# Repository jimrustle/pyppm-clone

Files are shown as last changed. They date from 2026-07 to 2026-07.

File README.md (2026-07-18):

#

This project is a modern update of [https://github.com/geekysuavo/pyppm](https://github.com/geekysuavo/pyppm).

All design credits go to geekysuavo.

see kicad/ppm-clone.pdf for schematic

# Changes

This project implements pyppm ver 2.2 in KiCAD 10.0 instead of gEDA.

- The CTX02-13665 and LT3439 have been replaced with a Wurth 78931812512 and TI SN6505BDBV due to the CTX02 becoming obsoleted

# Notes

No changes so far. Any parts changes will be performed in separate branches.

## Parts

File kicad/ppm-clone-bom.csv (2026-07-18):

Reference | Value | Footprint | Qty | LCSC P/N | Notes | Check | Digikey PN | LCSC qty
C1,C29,CB52,CT14 | 1u | Capacitor_SMD:C_0603_1608Metric_Pad1.08x0.95mm_HandSolder | 4 | C5673 | 25 V X5R | x | 490-5307-1-ND | 50
C2,C3 | 27p | Capacitor_SMD:C_0603_1608Metric_Pad1.08x0.95mm_HandSolder | 2 | C107045 |  | x | 490-1413-1-ND
C4,C5,C15,C18,C27,CB1,CB2,CB9,CB10,CB12,CB13,CB15,CB16,CB18,CB20,CB22,CB24,CB26,CB28,CB30,CB32,CB34,CB36,CB38,CB40,CB42,CB44,CB46,CB48,CB50,CB53,CB55,CB57,CB59,CB61,CB63,CT10 | 100n | Capacitor_SMD:C_0603_1608Metric_Pad1.08x0.95mm_HandSolder | 37 | C14663 |  | x | 490-1532-1-ND
C7 | 2.2n / 1kV | Capacitor_SMD:C_1206_3216Metric_Pad1.33x1.80mm_HandSolder | 1 | C9191 |  | x | 478-2953-1-ND
C8,C9,C11,C12 | 15u | Capacitor_SMD:C_0805_2012Metric_Pad1.18x1.45mm_HandSolder | 4 |  |  |  | 445-3927-1-ND
C10,C13,C14,C16,C19,C20,C21,C22,C23,C24,C25,C26,C28,C30 | 10n | Capacitor_SMD:C_0603_1608Metric_Pad1.08x0.95mm_HandSolder | 14 | C115056 |  | x | 445-2664-1-ND
C17 | 220p | Capacitor_SMD:C_0603_1608Metric_Pad1.08x0.95mm_HandSolder | 1 | C302060 | film to mlcc | x | PCF1445CT-ND
CB3,CB4,CB7,CB8,CB11,CB14,CB17,CB21,CB25,CB27,CB29,CB31,CB33,CB35,CB37,CB39,CB41,CB43,CB45,CB47,CB49,CB51,CB54,CB56,CB58,CB60,CB62 | 10u | Capacitor_SMD:C_0603_1608Metric_Pad1.08x0.95mm_HandSolder | 27 | C96446 | tantalum to mlcc | x | 511-1683-1-ND
CB5,CB6,CT16 | 4.7u | Capacitor_SMD:C_0603_1608Metric_Pad1.08x0.95mm_HandSolder | 3 | C19666 |  | x | 490-7199-1-ND
CB19,CB23 | 100u | Capacitor_SMD:CP_Elec_5x5.3 | 2 | C134722 | tant poly to alum | x | P16641CT-ND
CT1 | 150p | Capacitor_SMD:C_0603_1608Metric_Pad1.08x0.95mm_HandSolder | 1 | C107038 | film to mlcc | x | PCF1461CT-ND
CT2 | 330p | Capacitor_SMD:C_0603_1608Metric_Pad1.08x0.95mm_HandSolder | 1 | C1664 | film to mlcc | x | PCF1465CT-ND
CT3 | 680p | Capacitor_SMD:C_0603_1608Metric_Pad1.08x0.95mm_HandSolder | 1 | C107055 | film to mlcc | x | PCF1451CT-ND
CT4 | 1.5n | Capacitor_SMD:C_0603_1608Metric_Pad1.08x0.95mm_HandSolder | 1 | C576797 | film to mlcc | x | PCF1455CT-ND
CT5 | 3.3n | Capacitor_SMD:C_0603_1608Metric_Pad1.08x0.95mm_HandSolder | 1 | C3877267 | film to mlcc | x | PCF1171CT-ND
CT6 | 6.8n | Capacitor_SMD:C_0603_1608Metric_Pad1.08x0.95mm_HandSolder | 1 | C307492 | film to mlcc | x | PCF1175CT-ND
CT7 | 15n | Capacitor_SMD:C_0603_1608Metric_Pad1.08x0.95mm_HandSolder | 1 | C2833636 | film to mlcc | x | PCF1179CT-ND
CT8 | 33n | Capacitor_SMD:C_0603_1608Metric_Pad1.08x0.95mm_HandSolder | 1 | C106856 | film to mlcc | x | PCF1183CT-ND
CT9 | 68n | Capacitor_SMD:C_0603_1608Metric_Pad1.08x0.95mm_HandSolder | 1 | C107098 | film to mlcc | x | PCF1187CT-ND
CT11 | 220n | Capacitor_SMD:C_0603_1608Metric_Pad1.08x0.95mm_HandSolder | 1 | C344195 | film to mlcc | x | PCF1128CT-ND
CT12 | 330n | Capacitor_SMD:C_0603_1608Metric_Pad1.08x0.95mm_HandSolder | 1 | C282682 | film to mlcc | x | PCF1129CT-ND
CT13 | 680n | Capacitor_SMD:C_0603_1608Metric_Pad1.08x0.95mm_HandSolder | 1 | C5143539 | film to mlcc | x | PCF1131CT-ND
CT15 | 2.2u | Capacitor_SMD:C_0603_1608Metric_Pad1.08x0.95mm_HandSolder | 1 | C5184421 |  | x | 490-3296-1-ND
D3,D4,D6,D7 | BAS40-04 | Package_TO_SOT_SMD:SOT-23 | 4 | C40919 |  | x | BAS40-04-V-GS08CT-ND
D5 | BAV199 | Package_TO_SOT_SMD:SOT-23 | 1 | C40919 | bav199 | x | 568-1619-1-ND
D8 | S5GC-13-F | Diode_SMD:D_SMC-RM10_Universal_Handsoldering | 1 | C211400 |  | x | S5GC-FDICT-ND
D9 | SMDJ45A | Diode_SMD:D_SMC-RM10_Universal_Handsoldering | 1 | C4154731 |  | x | SMDJ45ACT-ND
D10 | BAT54W | Package_TO_SOT_SMD:SOT-323_SC-70 | 1 | C8657 | slower | x | SD101AWSTPMSCT-ND
DL1,DL2,DL3,DL4,DL5,DL6,DL7,DL8 | LED | LED_SMD:LED_0805_2012Metric_Pad1.15x1.40mm_HandSolder | 8 | C22371297 | 10 mA, 0603 | x | 160-1828-1-ND
J1 | USB_C_Receptacle_USB2.0_14P | Connector_USB:USB_C_Receptacle_HCTL_HC-TYPE-C-16P-01A | 1 | C2894897 |  | x
J2 | Barrel_Jack |  | 1 |  |  | x
K1 | G6A | Relay_THT:Relay_DPDT_Omron_G6A | 1 | C146834 |  | x | Z123-ND
L1,L2 | 33u | ppm-clone:SDR6603 | 2 |  | OUT OF STOCK
L3,L4,L5 | BLM18PG121SN1D | Inductor_SMD:L_0603_1608Metric_Pad1.05x0.95mm_HandSolder | 3 | C14709 |  | x | 490-1037-1-ND
LJ1,LJ2,LJ3 | Screw_Terminal_01x02 | TerminalBlock_TE-Connectivity:TerminalBlock_TE_282834-2_1x02_P2.54mm_Horizontal | 3 | C8465 |  | x
Q1 | STD20NF06T4 | Package_TO_SOT_SMD:TO-252-2 | 1 | C22366765 |  | x | IRLR024NPBFCT-ND
Q2 | DMN2230U | Package_TO_SOT_SMD:SOT-23 | 1 | C516590 | RDS worse |  | FDN327NCT-ND
R1,R2 | 22 | Resistor_SMD:R_0603_1608Metric_Pad0.98x0.95mm_HandSolder | 2 | C23345 |  |  | P22.0HCT-ND
R3,R4,R7,R20,R28,R29,R30,R31,R39,R40,R42,R49,R52 | 10k | Resistor_SMD:R_0603_1608Metric_Pad0.98x0.95mm_HandSolder | 13 | C2930027 |  |  | P10.0KHCT-ND
R5,R6 | 5.1k | Resistor_SMD:R_0603_1608Metric_Pad0.98x0.95mm_HandSolder | 2 | C2907114
R10,R12 | 1.05k | Resistor_SMD:R_0603_1608Metric_Pad0.98x0.95mm_HandSolder | 2 | C2930047 |  |  | P1.05KHCT-ND
R11,R13,R22,R23,R37,R51 | 1k | Resistor_SMD:R_0603_1608Metric_Pad0.98x0.95mm_HandSolder | 6 | C2907113 |  |  | P1.00KHCT-ND
R14,R15,R17,R19,R36 | 100k | Resistor_SMD:R_0603_1608Metric_Pad0.98x0.95mm_HandSolder | 5 | C14675 |  |  | P100KHCT-ND
R16 | 1.3M | Resistor_SMD:R_0603_1608Metric_Pad0.98x0.95mm_HandSolder | 1 | C2974026 |  |  | P1.3MGCT-ND
R18 | 1.5M | Resistor_SMD:R_0603_1608Metric_Pad0.98x0.95mm_HandSolder | 1 | C4172 |  |  | P1.5MGCT-ND
R21,R24 | 3.16k | Resistor_SMD:R_0603_1608Metric_Pad0.98x0.95mm_HandSolder | 2 | C2930087 |  |  | P3.16KHCT-ND
R25,R26,R27 | 330 | Resistor_SMD:R_0603_1608Metric_Pad0.98x0.95mm_HandSolder | 3 | C23138 |  |  | P330HCT-ND
R32,R33,R41 | 49.9 | Resistor_SMD:R_0603_1608Metric_Pad0.98x0.95mm_HandSolder | 3 | C2930110 |  |  | P49.9DBCT-ND
R34,R35,R44,R47 | 1M | Resistor_SMD:R_0603_1608Metric_Pad0.98x0.95mm_HandSolder | 4 | C22935 |  |  | A102234CT-ND
R38 | 10 | Resistor_SMD:R_0603_1608Metric_Pad0.98x0.95mm_HandSolder | 1 | C22859 |  |  | CRT0603-BY-10R0ELFCT-ND
R43,R46 | 0 | Resistor_SMD:R_0603_1608Metric_Pad0.98x0.95mm_HandSolder | 2 | C21189 |  |  | P0.0GCT-ND
R45,R48 | 715 | Resistor_SMD:R_0603_1608Metric_Pad0.98x0.95mm_HandSolder | 2 | C2998136 |  |  | P715DBCT-ND
R50 | 33.2 | Resistor_SMD:R_0603_1608Metric_Pad0.98x0.95mm_HandSolder | 1 | C2930093 |  |  | P33.2HCT-ND
RF1 | 14.3k | Resistor_SMD:R_0603_1608Metric_Pad0.98x0.95mm_HandSolder | 1 | C2933145 |  |  | P14.3KHCT-ND
RF2 | 15.4k | Resistor_SMD:R_0603_1608Metric_Pad0.98x0.95mm_HandSolder | 1 | C2933150 |  |  | P15.4KHCT-ND
RF3 | 45.3k | Resistor_SMD:R_0603_1608Metric_Pad0.98x0.95mm_HandSolder | 1 | C2933224 |  |  | P45.3KHCT-ND
RF4 | 5.49k | Resistor_SMD:R_0603_1608Metric_Pad0.98x0.95mm_HandSolder | 1 | C3000723 |  |  | P5.49KHCT-ND
RF5 | 6.04k | Resistor_SMD:R_0603_1608Metric_Pad0.98x0.95mm_HandSolder | 1 | C25977 |  |  | P6.04KHCT-ND
RF6 | 17.4k | Resistor_SMD:R_0603_1608Metric_Pad0.98x0.95mm_HandSolder | 1 | C2930069 |  |  | P17.4KHCT-ND
RF7 | 13.3k | Resistor_SMD:R_0603_1608Metric_Pad0.98x0.95mm_HandSolder | 1 | C2933140 |  |  | P13.3KHCT-ND
RF8 | 5.23k | Resistor_SMD:R_0603_1608Metric_Pad0.98x0.95mm_HandSolder | 1 | C2930111 |  |  | P5.23KHCT-ND
RF9 | 232k | Resistor_SMD:R_0603_1608Metric_Pad0.98x0.95mm_HandSolder | 1 | C2998117 |  |  | P232KHCT-ND
RF10 | 2k | Resistor_SMD:R_0603_1608Metric_Pad0.98x0.95mm_HandSolder | 1 | C2907137 |  |  | P2.00KHCT-ND
RF11 | 732 | Resistor_SMD:R_0603_1608Metric_Pad0.98x0.95mm_HandSolder | 1 | C245063 |  |  | P732HCT-ND
RF12 | 34.8k | Resistor_SMD:R_0603_1608Metric_Pad0.98x0.95mm_HandSolder | 1 | C23141 |  |  | P34.8KHCT-ND
RL1,RL2,RL3,RL4,RL5,RL6,RL7,RL8 | 100 | Resistor_SMD:R_0603_1608Metric_Pad0.98x0.95mm_HandSolder | 8 |  | 500 ohm |  | P604HCT-ND
RY1 | ACSL-6300 | Package_SO:SO-16_3.9x9.9mm_P1.27mm | 1 | C6800668 |  |  | 516-2221-1-ND
SW1,SW2 | SW_Push | Button_Switch_SMD:SW_SPST_B3S-1000 | 2 |  | OUT OF STOCK
T1 | 78931812512 | Transformer_SMD:Transformer_Wuerth_750315371 | 1 |  | OUT OF STOCK
U1 | ATmega32U4-A | Package_QFP:TQFP-44_10x10mm_P0.8mm | 1 | C2052746 |  |  | ATMEGA32U4-AU-ND | 3
U3 | SN6505BDBV | Package_TO_SOT_SMD:SOT-23-6 | 1 | C2156022 |  |  | LT3439EFE#PBF-ND | 3
U4 | LT1761-5 | Package_TO_SOT_SMD:TSOT-23-5 | 1 | C655160 |  |  | LT1761ES5-5#TRMPBFCT-ND | 3
U5 | LT1964-5 | Package_TO_SOT_SMD:TSOT-23-5 | 1 | C5357091 |  |  | LT1964ES5-5#TRMPBFCT-ND | 3
U6 | LT1761-SD | Package_TO_SOT_SMD:TSOT-23-5 | 1 | C117432 |  |  | LT1761ES5-SD#TRMPBFCT-ND | 3
U7 | LT1964-SD | Package_TO_SOT_SMD:TSOT-23-5 | 1 | C117431 |  |  | LT1964ES5-SD#TRMPBFCT-ND | 3
U8 | LTC2909 | Package_TO_SOT_SMD:TSOT-23-8_HandSoldering | 1 |  | OUT OF STOCK |  | LTC2909CTS8-5#TRMPBFCT-ND
U9 | LT1764AEQ | Package_TO_SOT_SMD:TO-263-5_TabPin3 | 1 | C459712 |  |  | LT1764AEQ#TRPBFCT-ND | 3
U10 | LT3015xQ-5 | Package_TO_SOT_SMD:TO-263-5_TabPin3 | 1 | C666317 |  |  | LT3015EQ#PBF-ND | 3
U12,U13 | ADG714 | Package_SO:TSSOP-24_4.4x7.8mm_P0.65mm | 2 | C462201 |  |  | ADG714BRUZ-REEL7CT-ND | 3
U14 | AD8428 | Package_SO:SOIC-8_3.9x4.9mm_P1.27mm | 1 |  | OUT OF STOCK |  | AD8428ARZ-ND
U15 | AD8597 | Package_SO:SOIC-8_3.9x4.9mm_P1.27mm | 1 | C209450 |  |  | AD8597ARZ-ND | 3
U16 | OP462 | Package_SO:TSSOP-14_4.4x5mm_P0.65mm | 1 |  | OUT OF STOCK |  | OP462HRUZ-REELCT-ND
U17 | ADA4841-1YRJ | Package_TO_SOT_SMD:SOT-23-6 | 1 | C578930 |  |  | ADA4841-1YRJZ-R7CT-ND | 3
U18 | AD7680ARMZ | Package_TO_SOT_SMD:SOT-23-6 | 1 | C578464 |  |  | AD7680ARJZ-REEL7CT-ND | 3
U19 | AD5752 | Package_SO:HTSSOP-24-1EP_4.4x7.8mm_P0.65mm_EP3.2x5mm | 1 |  | OUT OF STOCK |  | AD5752RBREZ-ND
U20 | ADR4520 | Package_SO:SOIC-8_3.9x4.9mm_P1.27mm | 1 | C579305 |  |  | ADR4520BRZ-ND | 3
U21 | LT1206CS8 | Package_SO:SO-8_3.9x4.9mm_P1.27mm | 1 | C579690 |  |  | LT1206CS8#PBF-ND | 3
U22 | LT1210 | Package_TO_SOT_SMD:TO-263-7_TabPin4 | 1 | C1349277 |  |  | LT1210CR#PBF-ND | 3
U23 | FAN3111E | Package_TO_SOT_SMD:SOT-23-5 | 1 | C719836 |  |  | FAN3111ESXCT-ND | 15
Y1 | 16M | Crystal:Crystal_SMD_Abracon_ABM7-2Pin_6.0x3.5mm | 1 | 535-9840-1-ND | OUT OF STOCK |  | 535-9840-1-ND

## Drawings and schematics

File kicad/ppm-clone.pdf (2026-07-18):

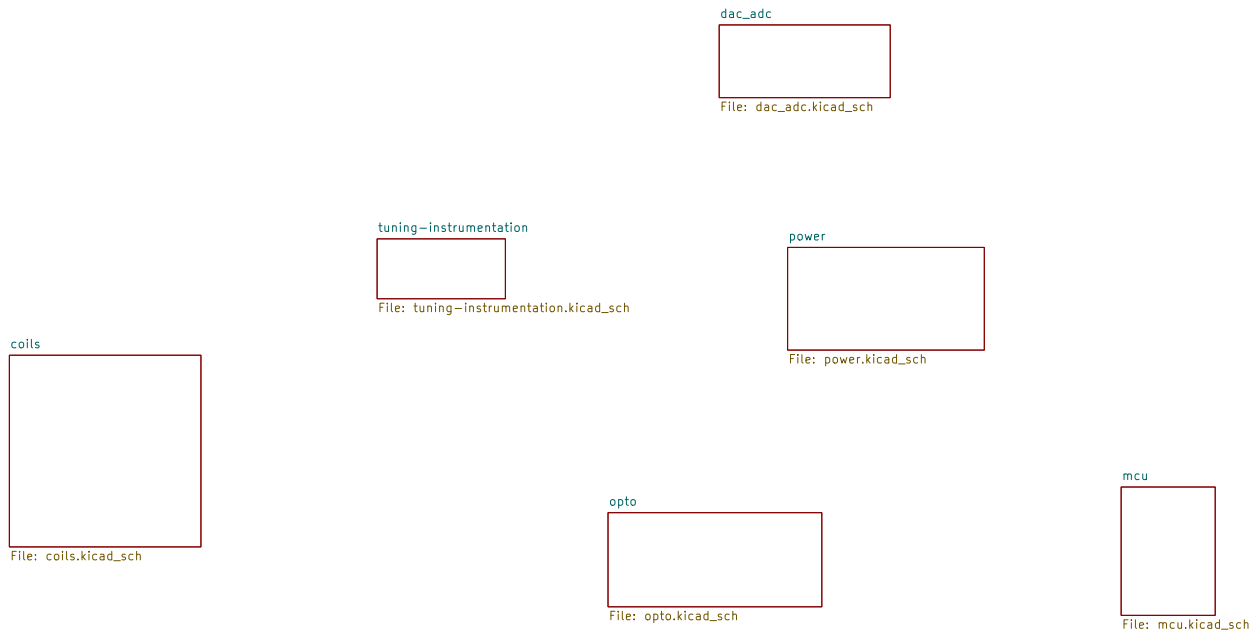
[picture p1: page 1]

Size: A4 | Rev:
KiCad E.D.A. 10.0.1 | Id: 1/7

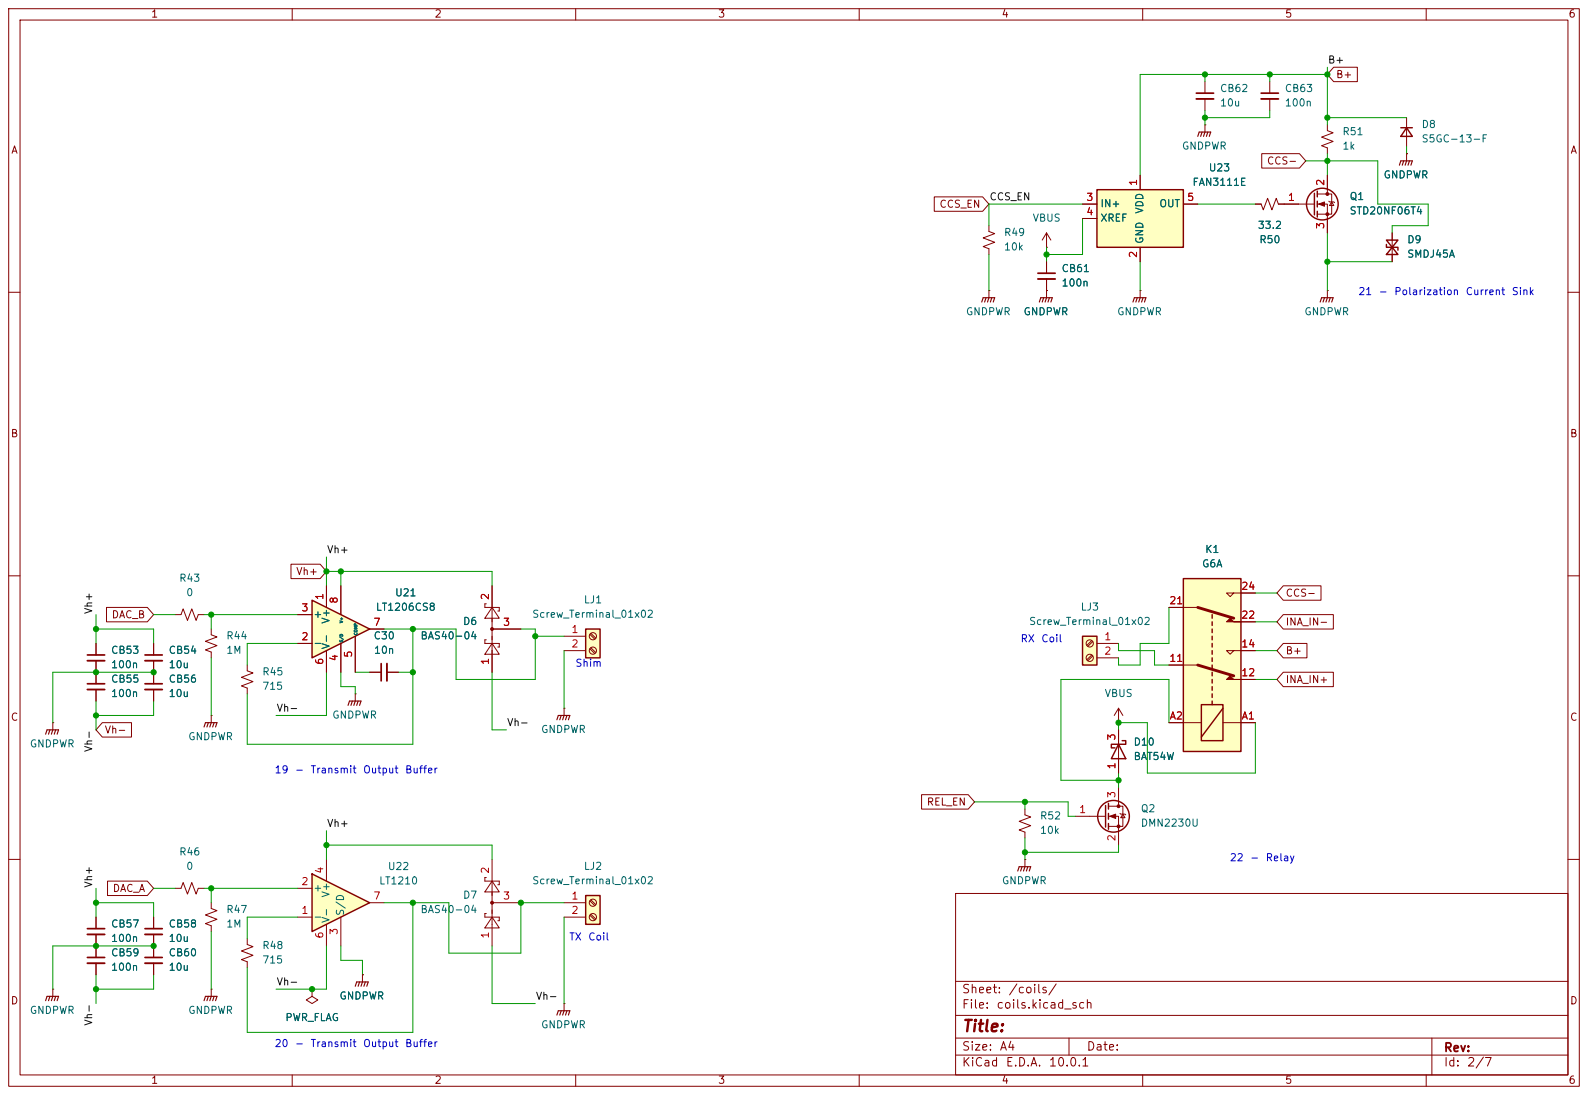
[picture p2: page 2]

21 - Polarization Current Sink Shim

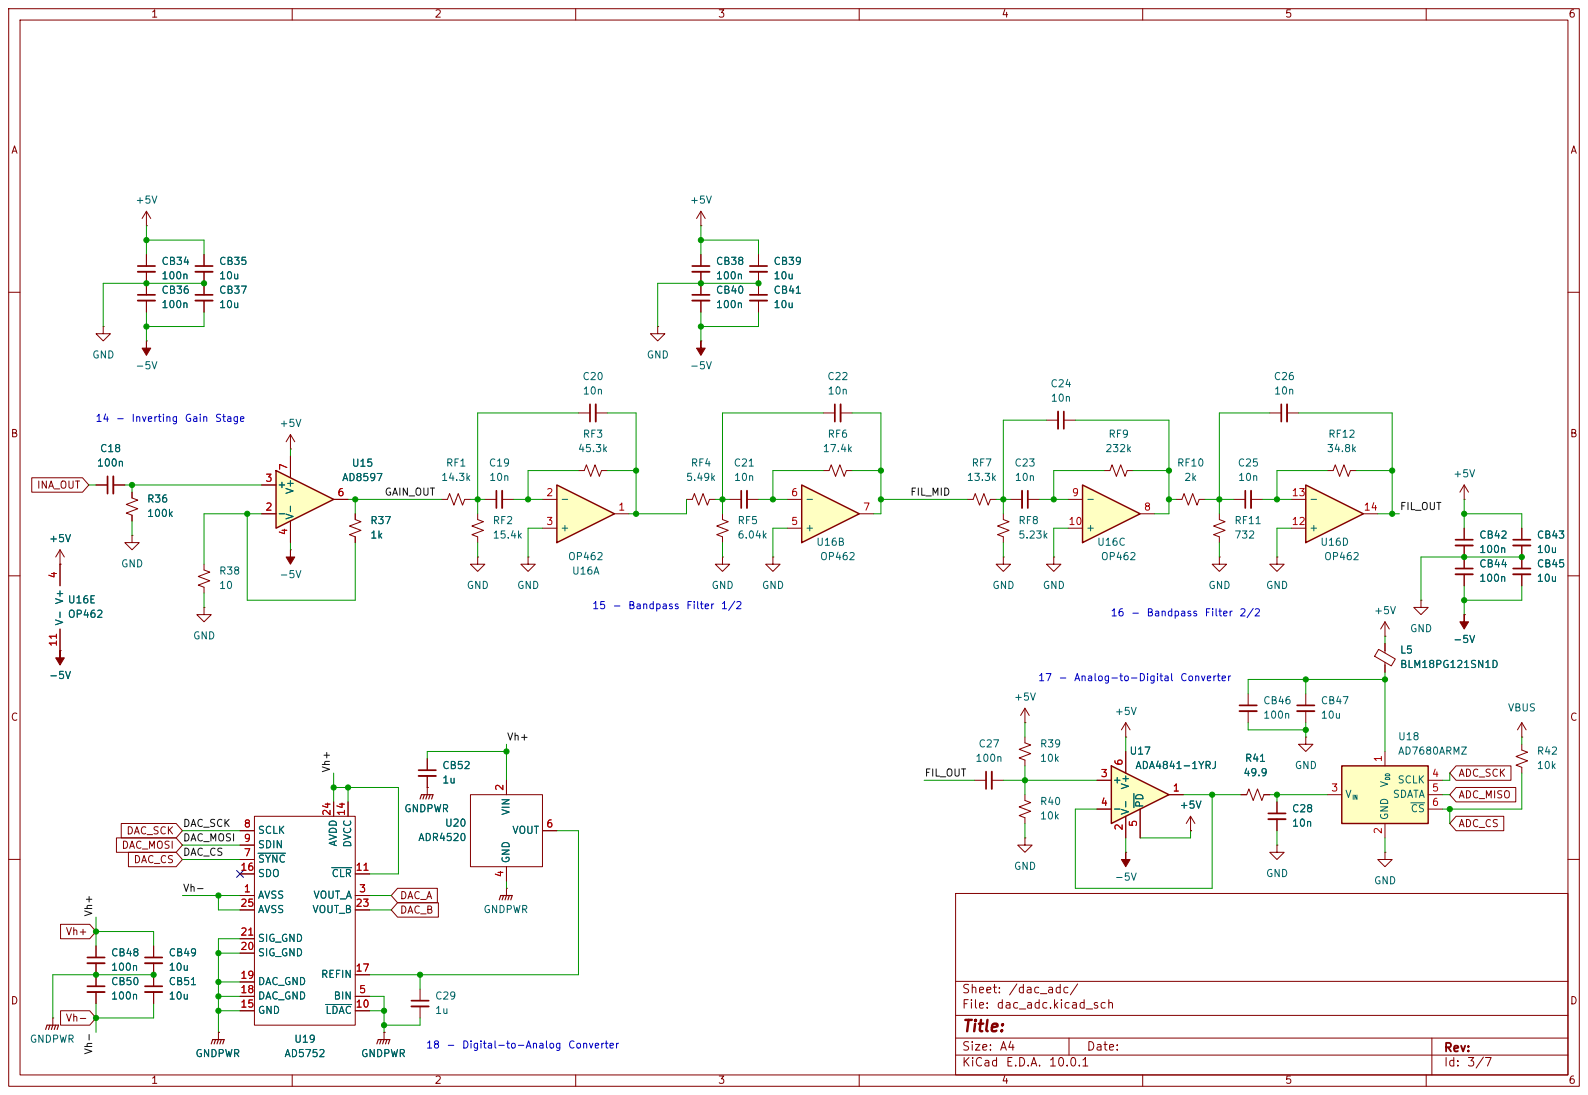
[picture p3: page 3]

17 - Analog-to-Digital Converter 14 - Inverting Gain Stage

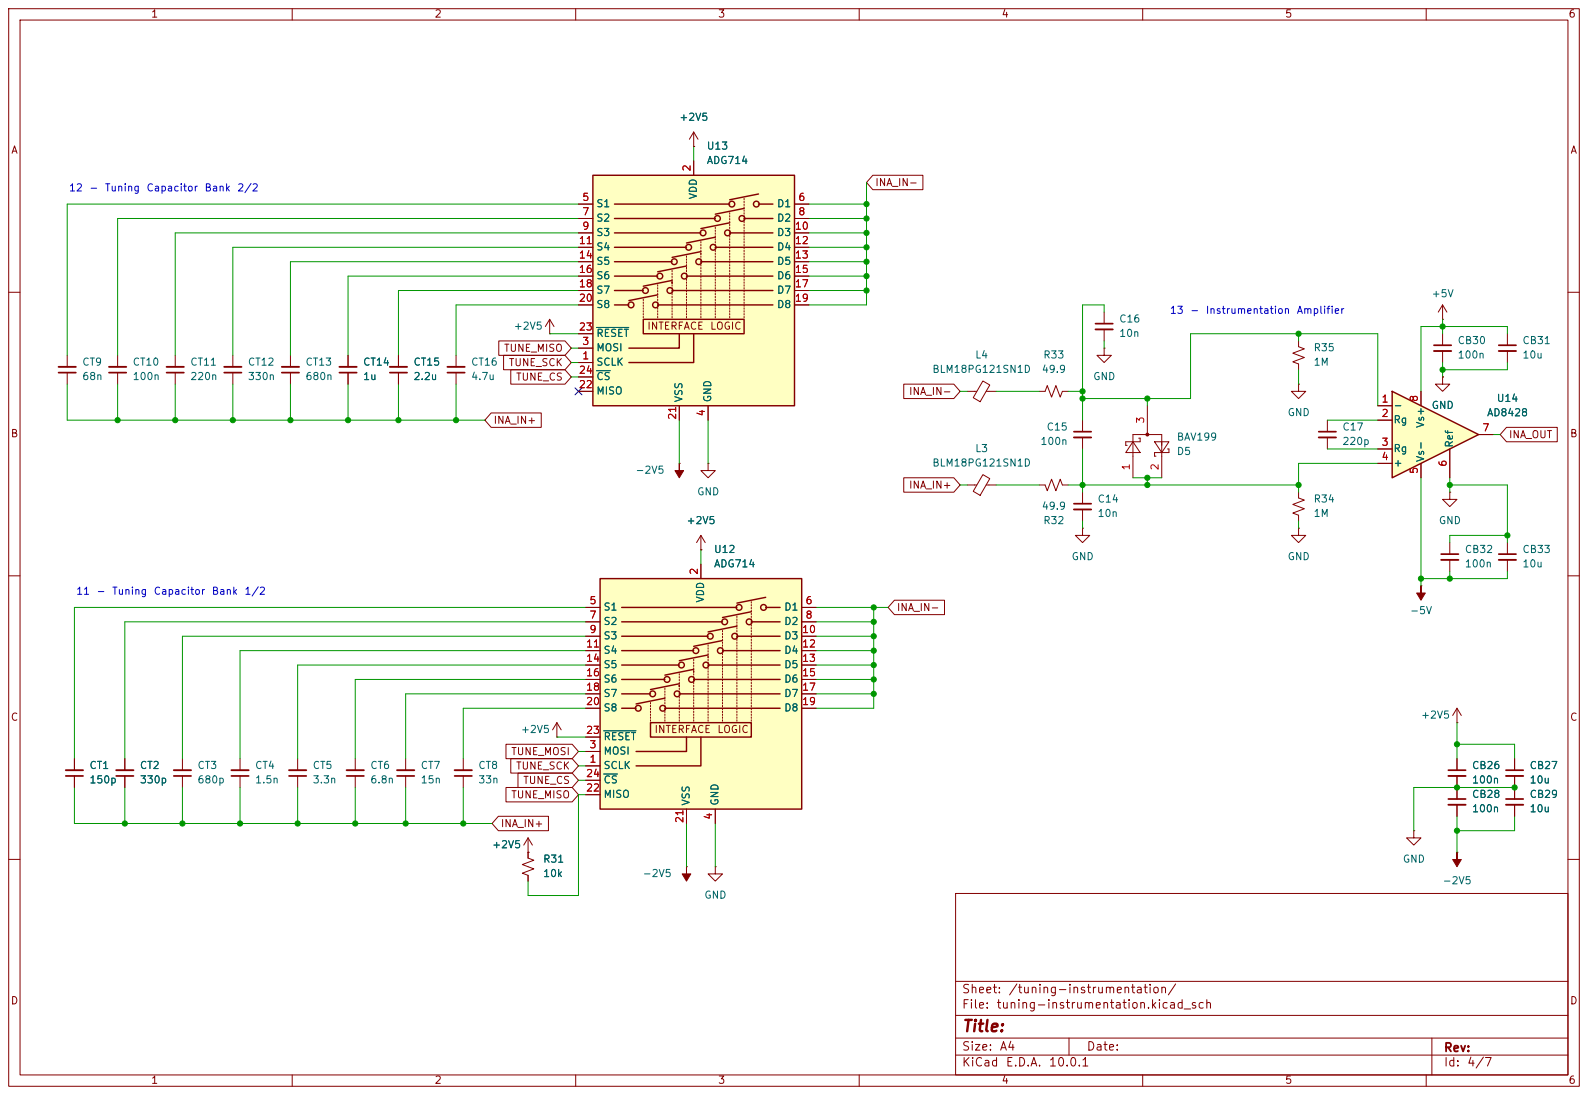
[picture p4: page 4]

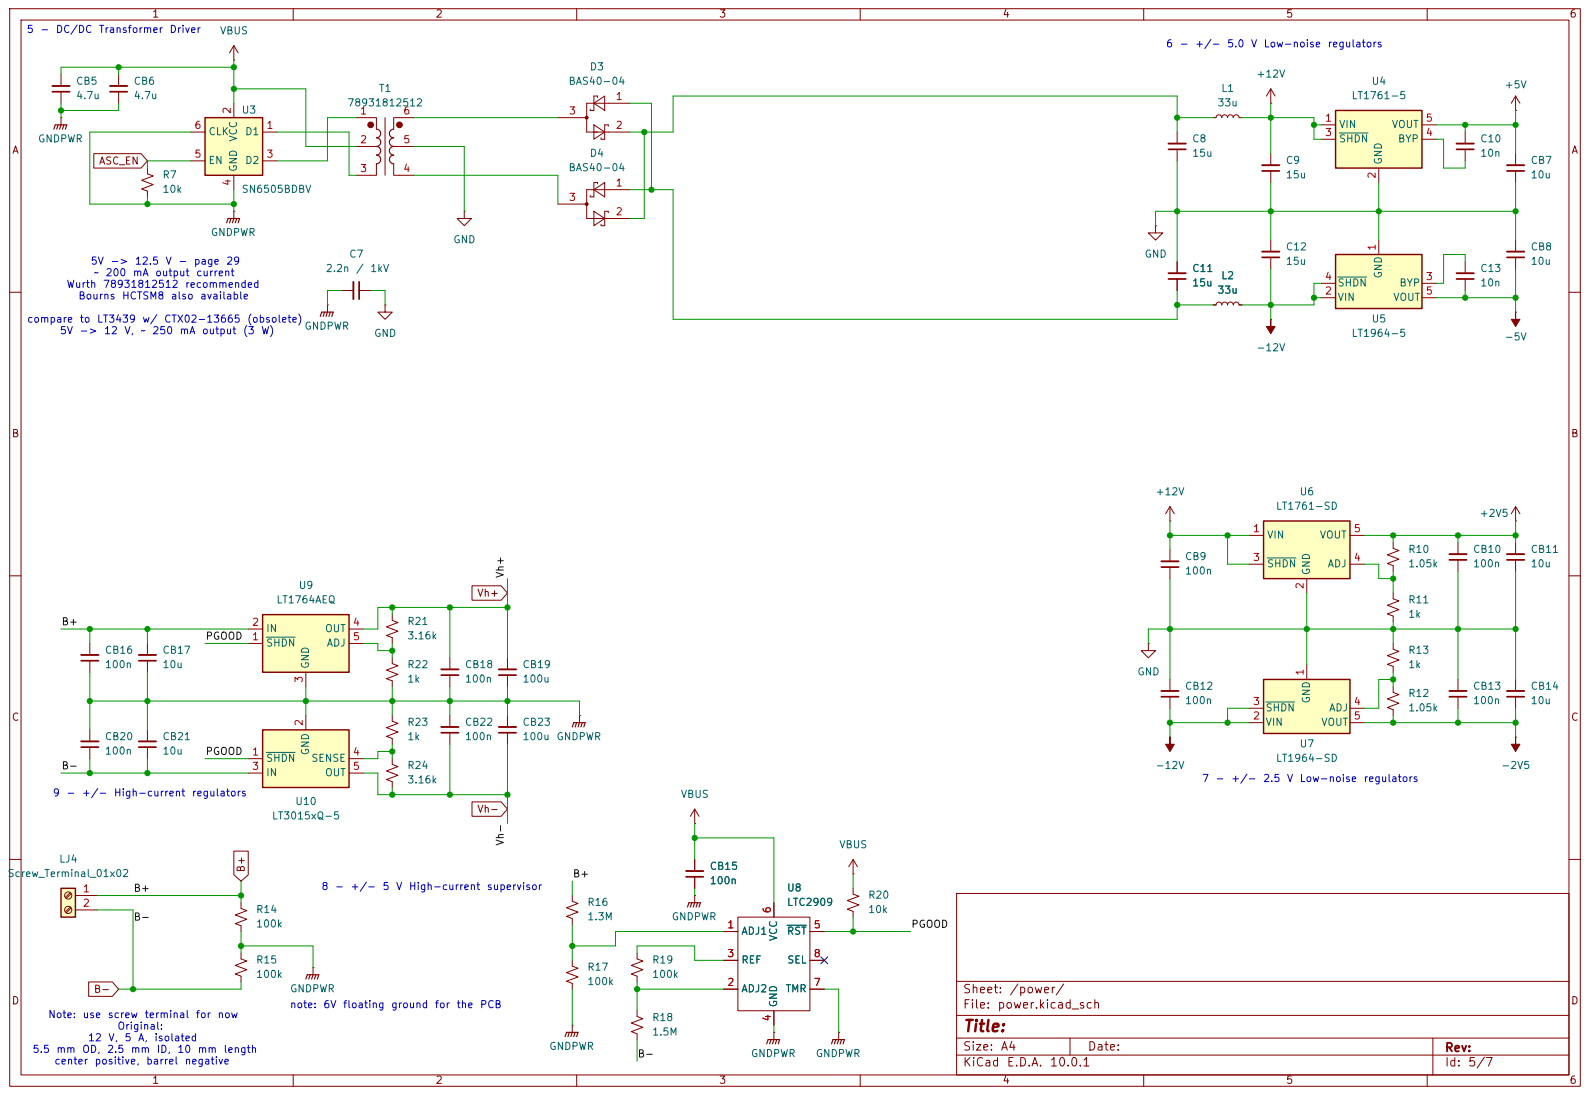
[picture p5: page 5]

6 - +/- 5.0 V Low-noise regulators 5 - DC/DC Transformer Driver 5V -> 12.5 V - page 29
3 D4 BAS40-04 R23

compare to LT3439 w/ CTX02-13665 (obsolete) 5V -> 12 V, ~ 250 mA output (3 W) Note: use screw terminal for now

~ 200 mA output current Wurth 78931812512 recommended Bourns HCTSM8 also available

Original: 12 V, 5 A, isolated 5.5 mm OD, 2.5 mm ID, 10 mm length

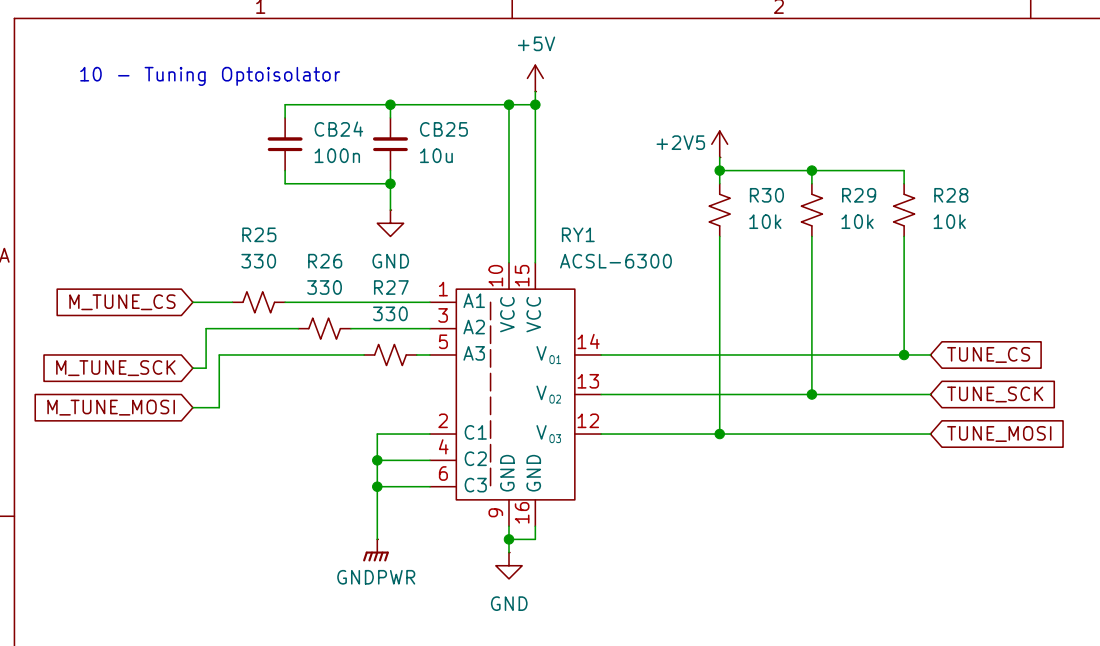
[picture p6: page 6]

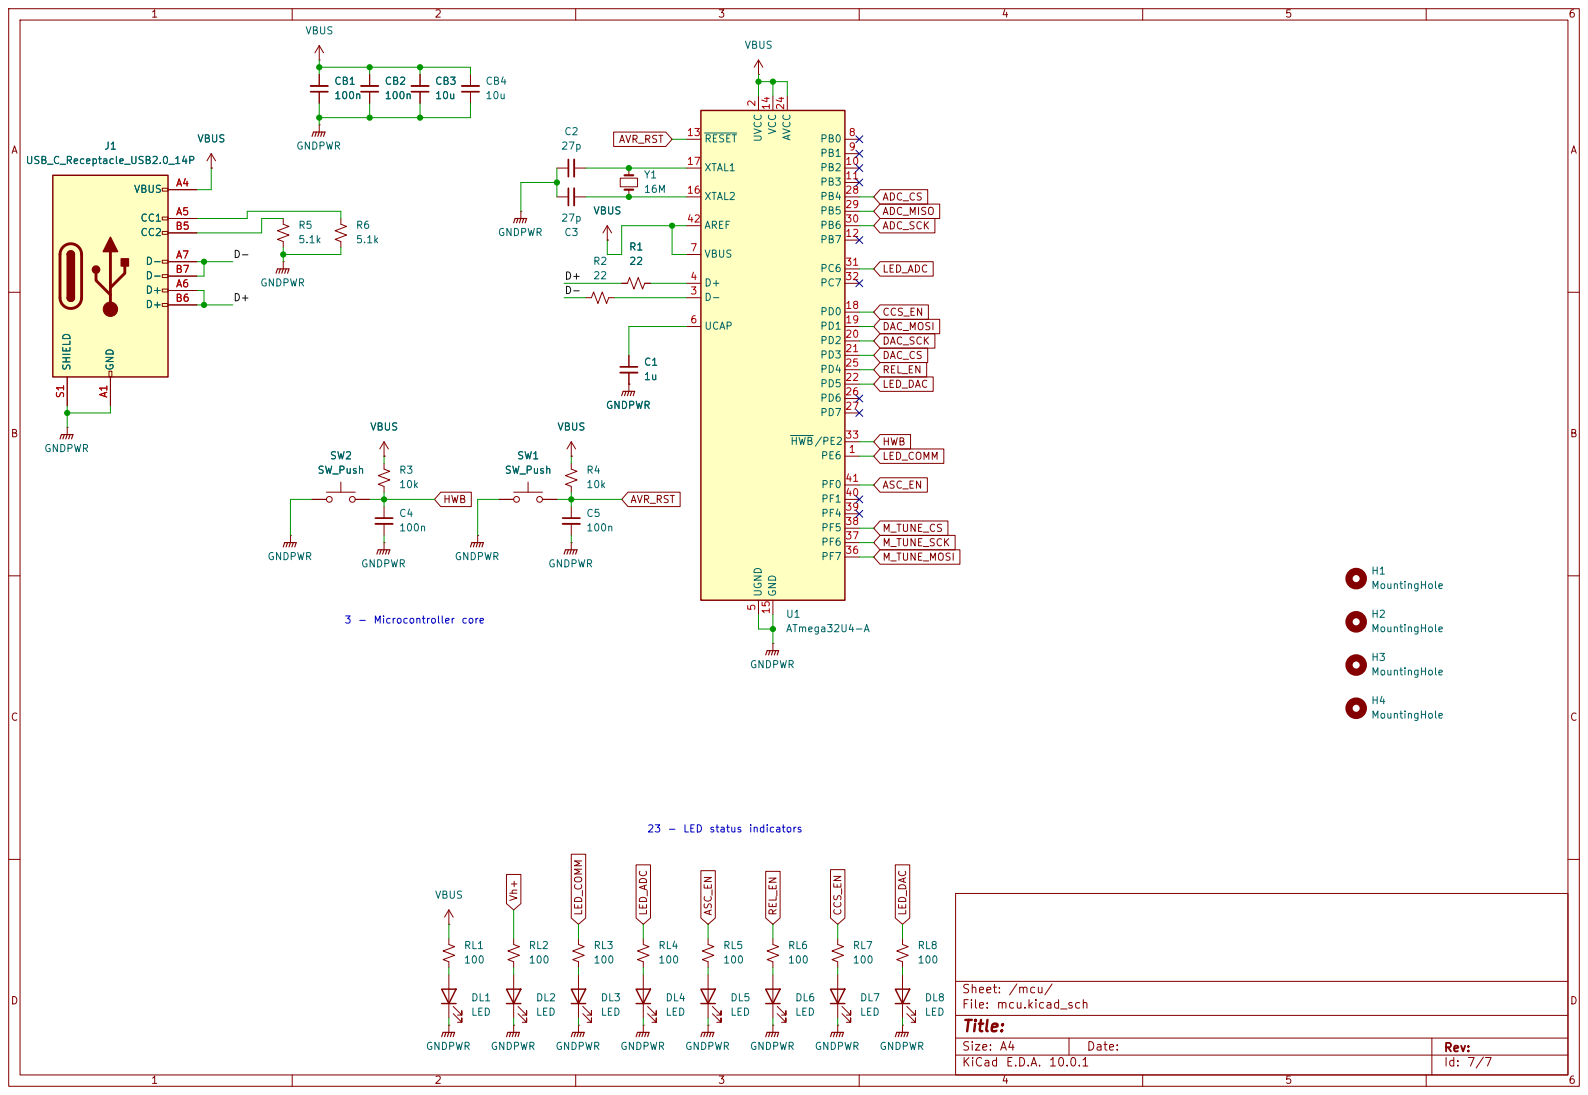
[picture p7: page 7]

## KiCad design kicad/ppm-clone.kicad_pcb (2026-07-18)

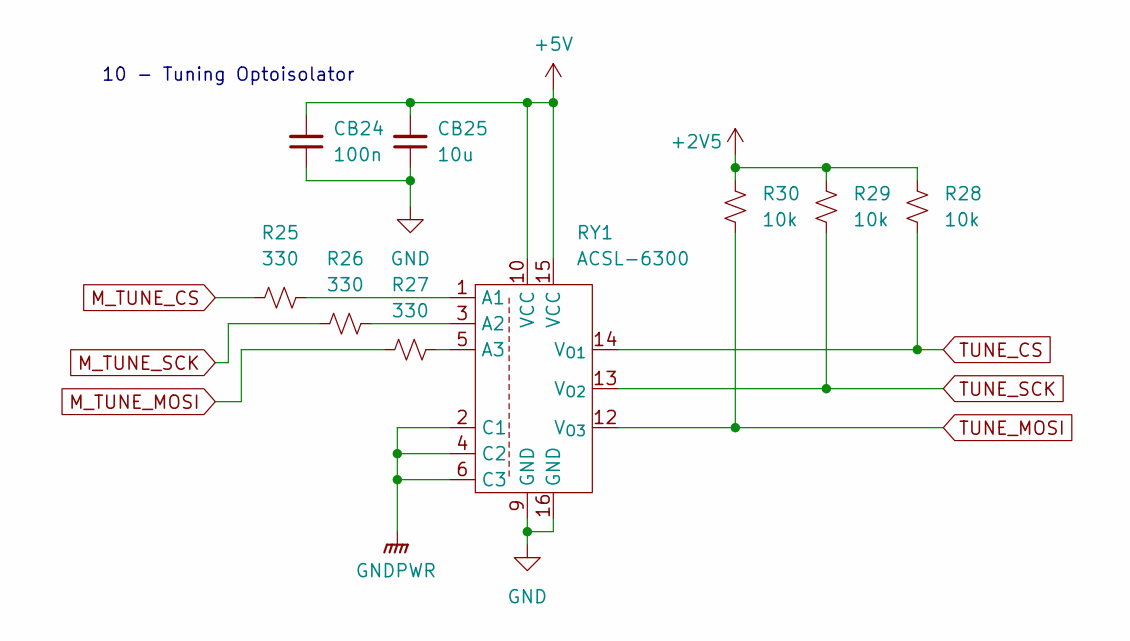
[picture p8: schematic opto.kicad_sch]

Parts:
CB24: 100n; C_0603_1608Metric_Pad1.08x0.95mm_HandSolder
CB25: 10u; C_0603_1608Metric_Pad1.08x0.95mm_HandSolder
R25, R26, R27: 330; R_0603_1608Metric_Pad0.98x0.95mm_HandSolder
R28, R29, R30: 10k; R_0603_1608Metric_Pad0.98x0.95mm_HandSolder
RY1: ACSL-6300; SO-16_3.9x9.9mm_P1.27mm

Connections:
+2V5: R28.1, R29.1, R30.1; also elsewhere on the board
+5V: CB24.2, CB25.2, RY1.10 (VCC), RY1.15 (VCC); also elsewhere on the board
GND: CB24.1, CB25.1, RY1.9 (GND), RY1.16 (GND); also elsewhere on the board
GNDPWR: RY1.2 (C1), RY1.4 (C2), RY1.6 (C3); also elsewhere on the board
M_TUNE_CS: R25.2; also elsewhere on the board
M_TUNE_MOSI: R27.2; also elsewhere on the board
M_TUNE_SCK: R26.2; also elsewhere on the board
unnamed: R25.1, RY1.1 (A1)
unnamed: R26.1, RY1.3 (A2)
unnamed: R27.1, RY1.5 (A3)
TUNE_CS: R28.2, RY1.14 (V_{O1}); also elsewhere on the board
TUNE_MOSI: R30.2, RY1.12 (V_{O3}); also elsewhere on the board
TUNE_SCK: R29.2, RY1.13 (V_{O2}); also elsewhere on the board

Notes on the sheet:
10 - Tuning Optoisolator

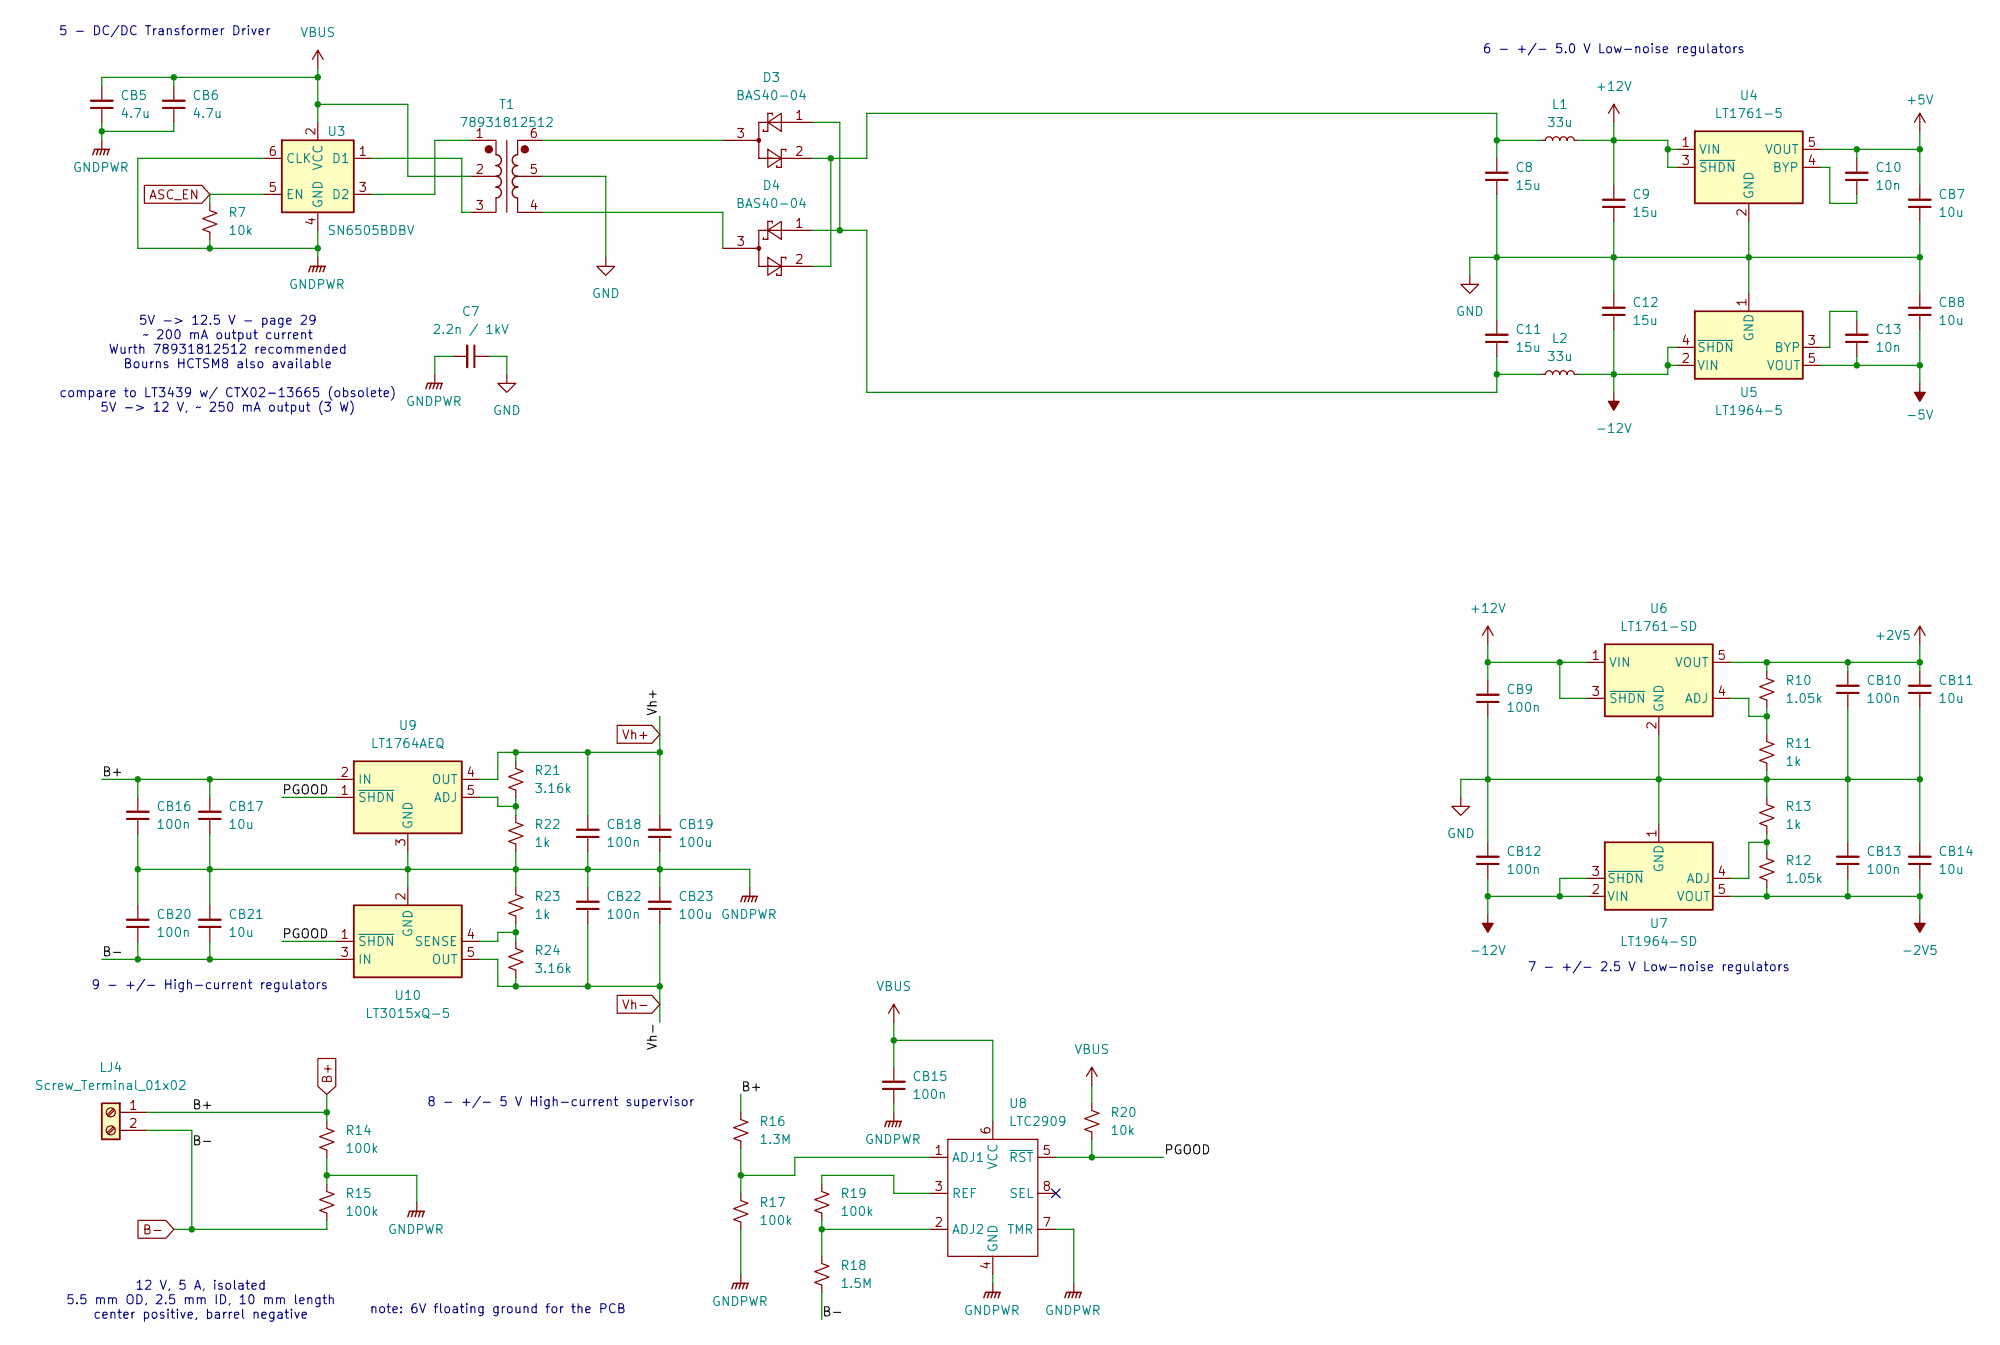
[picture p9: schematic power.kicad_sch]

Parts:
C7: 2.2n / 1kV; C_1206_3216Metric_Pad1.33x1.80mm_HandSolder
C8, C9, C11, C12: 15u; C_2220_5750Metric_Pad1.97x5.40mm_HandSolder
C10, C13: 10n; C_0603_1608Metric_Pad1.08x0.95mm_HandSolder
CB5, CB6: 4.7u; C_0603_1608Metric_Pad1.08x0.95mm_HandSolder
CB7, CB8, CB11, CB14, CB17, CB21: 10u; C_0603_1608Metric_Pad1.08x0.95mm_HandSolder
CB9, CB10, CB12, CB13, CB15, CB16, CB18, CB20, CB22: 100n; C_0603_1608Metric_Pad1.08x0.95mm_HandSolder
CB19, CB23: 100u; CP_Elec_5x5.3
D3, D4: BAS40-04; SOT-23
L1, L2: 33u; SDR6603
LJ4: Screw_Terminal_01x02; TerminalBlock_bornier-2_P5.08mm
R7, R20: 10k; R_0603_1608Metric_Pad0.98x0.95mm_HandSolder
R10, R12: 1.05k; R_0603_1608Metric_Pad0.98x0.95mm_HandSolder
R11, R13, R22, R23: 1k; R_0603_1608Metric_Pad0.98x0.95mm_HandSolder
R14, R15, R17, R19: 100k; R_0603_1608Metric_Pad0.98x0.95mm_HandSolder
R16: 1.3M; R_0603_1608Metric_Pad0.98x0.95mm_HandSolder
R18: 1.5M; R_0603_1608Metric_Pad0.98x0.95mm_HandSolder
R21, R24: 3.16k; R_0603_1608Metric_Pad0.98x0.95mm_HandSolder
T1: 78931812512; Transformer_Wuerth_750315371
U3: SN6505BDBV; SOT-23-6
U4: LT1761-5; TSOT-23-5
U5: LT1964-5; TSOT-23-5
U6: LT1761-SD; TSOT-23-5
U7: LT1964-SD; TSOT-23-5
U8: LTC2909; TSOT-23-8_HandSoldering
U9: LT1764AEQ; TO-263-5_TabPin3
U10: LT3015xQ-5; TO-263-5_TabPin3

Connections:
+2V5: CB10.2, CB11.2, R10.1, U6.5 (VOUT); also elsewhere on the board
+5V: C10.2, CB7.2, U4.5 (VOUT); also elsewhere on the board
+12V: C9.2, CB9.2, L1.2, U4.1 (VIN), U4.3 (~SHDN), U6.1 (VIN), U6.3 (~SHDN)
-2V5: CB13.1, CB14.1, R12.2, U7.5 (VOUT); also elsewhere on the board
-5V: C13.1, CB8.1, U5.5 (VOUT); also elsewhere on the board
-12V: C12.1, CB12.1, L2.2, U5.2 (VIN), U5.4 (~SHDN), U7.2 (VIN), U7.3 (~SHDN)
/power/PGOOD: R20.2, U8.5 (~RST), U9.1 (~SHDN), U10.1 (~SHDN)
ASC_EN: R7.1, U3.5 (EN); also elsewhere on the board
B+: CB16.2, CB17.2, LJ4.1, R14.1, R16.1, U9.2 (IN); also elsewhere on the board
B-: CB20.1, CB21.1, LJ4.2, R15.2, R18.2, U10.3 (IN)
GND: C7.1, C8.1, C9.1, C11.2, C12.2, CB7.1, CB8.2, CB9.1, CB10.1, CB11.1, CB12.2, CB13.2, CB14.2, R11.2, R13.1, T1.5, U4.2 (GND), U5.1 (GND), U6.2 (GND), U7.1 (GND); also elsewhere on the board
GNDPWR: C7.2, CB5.1, CB6.1, CB15.1, CB16.1, CB17.1, CB18.1, CB19.1, CB20.2, CB21.2, CB22.2, CB23.2, R7.2, R14.2, R15.1, R17.2, R22.2, R23.1, U3.4 (GND), U3.6 (CLK), U8.4 (GND), U8.7 (TMR), U9.3 (GND), U10.2 (GND); also elsewhere on the board
unnamed: C8.2, D3.2, D4.2, L1.1
unnamed: C11.1, D3.1, D4.1, L2.1
unnamed: D3.3, T1.6
unnamed: D4.3, T1.4
unnamed: T1.3, U3.1 (D1)
unnamed: T1.1, U3.3 (D2)
unnamed: C10.1, U4.4 (BYP)
unnamed: C13.2, U5.3 (BYP)
unnamed: R10.2, R11.1, U6.4 (ADJ)
unnamed: R12.1, R13.2, U7.4 (ADJ)
unnamed: R16.2, R17.1, U8.1 (ADJ1)
unnamed: R18.1, R19.2, U8.2 (ADJ2)
unnamed: R19.1, U8.3 (REF)
unnamed: R21.2, R22.1, U9.5 (ADJ)
unnamed: R23.2, R24.1, U10.4 (SENSE)
VBUS: CB5.2, CB6.2, CB15.2, R20.1, T1.2, U3.2 (VCC), U8.6 (VCC); also elsewhere on the board
Vh+: CB18.2, CB19.2, R21.1, U9.4 (OUT); also elsewhere on the board
Vh-: CB22.1, CB23.1, R24.2, U10.5 (OUT); also elsewhere on the board

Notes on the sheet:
8 - +/- 5 V High-current supervisor
9 - +/- High-current regulators
5V -> 12.5 V - page 29 ~ 200 mA output current Wurth 78931812512 recommended Bourns HCTSM8 also available compare to LT3439 w/ CTX02-13665 (obsolete) 5V -> 12 V, ~ 250 mA output (3 W)
7 - +/- 2.5 V Low-noise regulators
5 - DC/DC Transformer Driver
12 V, 5 A, isolated 5.5 mm OD, 2.5 mm ID, 10 mm length center positive, barrel negative
note: 6V floating ground for the PCB
6 - +/- 5.0 V Low-noise regulators

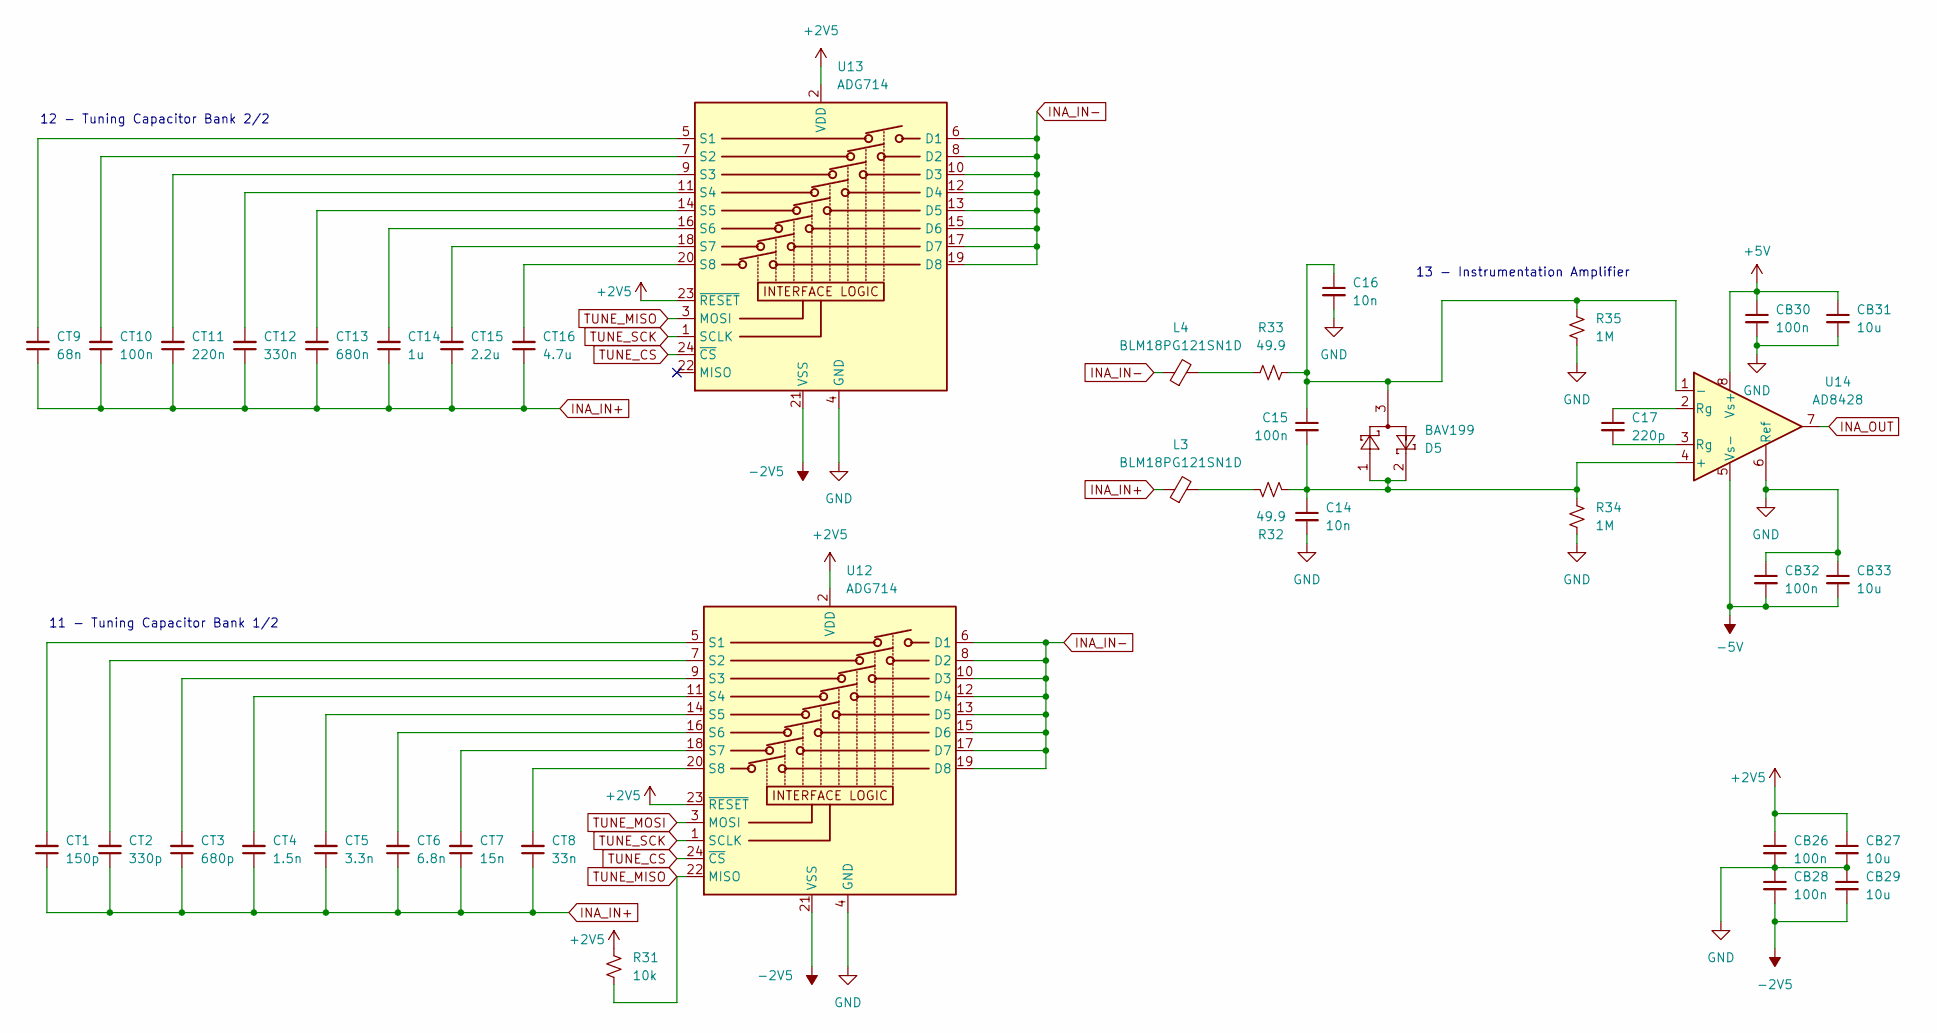
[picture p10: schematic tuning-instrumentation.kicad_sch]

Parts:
C14, C16: 10n; C_0603_1608Metric_Pad1.08x0.95mm_HandSolder
C15: 100n; C_0603_1608Metric_Pad1.08x0.95mm_HandSolder
C17: 220p; C_0603_1608Metric_Pad1.08x0.95mm_HandSolder
CB26, CB28, CB30, CB32: 100n; C_0603_1608Metric_Pad1.08x0.95mm_HandSolder
CB27, CB29, CB31, CB33: 10u; C_0603_1608Metric_Pad1.08x0.95mm_HandSolder
CT1: 150p; C_0603_1608Metric_Pad1.08x0.95mm_HandSolder
CT2: 330p; C_0603_1608Metric_Pad1.08x0.95mm_HandSolder
CT3: 680p; C_0603_1608Metric_Pad1.08x0.95mm_HandSolder
CT4: 1.5n; C_0603_1608Metric_Pad1.08x0.95mm_HandSolder
CT5: 3.3n; C_0603_1608Metric_Pad1.08x0.95mm_HandSolder
CT6: 6.8n; C_0603_1608Metric_Pad1.08x0.95mm_HandSolder
CT7: 15n; C_0603_1608Metric_Pad1.08x0.95mm_HandSolder
CT8: 33n; C_0603_1608Metric_Pad1.08x0.95mm_HandSolder
CT9: 68n; C_0603_1608Metric_Pad1.08x0.95mm_HandSolder
CT10: 100n; C_0603_1608Metric_Pad1.08x0.95mm_HandSolder
CT11: 220n; C_0603_1608Metric_Pad1.08x0.95mm_HandSolder
CT12: 330n; C_0603_1608Metric_Pad1.08x0.95mm_HandSolder
CT13: 680n; C_0603_1608Metric_Pad1.08x0.95mm_HandSolder
CT14: 1u; C_0603_1608Metric_Pad1.08x0.95mm_HandSolder
CT15: 2.2u; C_0603_1608Metric_Pad1.08x0.95mm_HandSolder
CT16: 4.7u; C_0603_1608Metric_Pad1.08x0.95mm_HandSolder
D5: BAV199; SOT-23
L3, L4: BLM18PG121SN1D; L_0603_1608Metric_Pad1.05x0.95mm_HandSolder
R31: 10k; R_0603_1608Metric_Pad0.98x0.95mm_HandSolder
R32, R33: 49.9; R_0603_1608Metric_Pad0.98x0.95mm_HandSolder
R34, R35: 1M; R_0603_1608Metric_Pad0.98x0.95mm_HandSolder
U12, U13: ADG714; TSSOP-24_4.4x7.8mm_P0.65mm
U14: AD8428; SOIC-8_3.9x4.9mm_P1.27mm

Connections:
+2V5: CB26.1, CB27.1, R31.2, U12.2 (VDD), U12.23 (~RESET), U13.2 (VDD), U13.23 (~RESET); also elsewhere on the board
+5V: CB30.1, CB31.1, U14.8 (Vs+); also elsewhere on the board
-2V5: CB28.2, CB29.2, U12.21 (VSS), U13.21 (VSS); also elsewhere on the board
-5V: CB32.2, CB33.2, U14.5 (Vs-); also elsewhere on the board
GND: C14.2, C16.2, CB26.2, CB27.2, CB28.1, CB29.1, CB30.2, CB31.2, CB32.1, CB33.1, R34.2, R35.2, U12.4 (GND), U13.4 (GND), U14.6 (Ref); also elsewhere on the board
INA_IN+: CT1.1, CT2.1, CT3.1, CT4.1, CT5.1, CT6.1, CT7.1, CT8.1, CT9.1, CT10.1, CT11.1, CT12.1, CT13.1, CT14.1, CT15.1, CT16.1, L3.1; also elsewhere on the board
INA_IN-: L4.1, U12.6 (D1), U12.8 (D2), U12.10 (D3), U12.12 (D4), U12.13 (D5), U12.15 (D6), U12.17 (D7), U12.19 (D8), U13.6 (D1), U13.8 (D2), U13.10 (D3), U13.12 (D4), U13.13 (D5), U13.15 (D6), U13.17 (D7), U13.19 (D8); also elsewhere on the board
INA_OUT: U14.7; also elsewhere on the board
unnamed: C17.1, U14.2 (Rg)
unnamed: C17.2, U14.3 (Rg)
unnamed: L3.2, R32.1
unnamed: L4.2, R33.1
unnamed: CT1.2, U12.5 (S1)
unnamed: CT2.2, U12.7 (S2)
unnamed: CT3.2, U12.9 (S3)
unnamed: CT4.2, U12.11 (S4)
unnamed: CT5.2, U12.14 (S5)
unnamed: CT6.2, U12.16 (S6)
unnamed: CT7.2, U12.18 (S7)
unnamed: CT8.2, U12.20 (S8)
unnamed: CT9.2, U13.5 (S1)
unnamed: CT10.2, U13.7 (S2)
unnamed: CT11.2, U13.9 (S3)
unnamed: CT12.2, U13.11 (S4)
unnamed: CT13.2, U13.14 (S5)
unnamed: CT14.2, U13.16 (S6)
unnamed: CT15.2, U13.18 (S7)
unnamed: CT16.2, U13.20 (S8)
unnamed: C14.1, C15.2, D5.1, D5.2, R32.2, R34.1, U14.4 (+)
unnamed: C15.1, C16.1, D5.3, R33.2, R35.1, U14.1 (-)
TUNE_CS: U12.24 (~CS), U13.24 (~CS); also elsewhere on the board
TUNE_MISO: R31.1, U12.22 (MISO), U13.3 (MOSI)
TUNE_MOSI: U12.3 (MOSI); also elsewhere on the board
TUNE_SCK: U12.1 (SCLK), U13.1 (SCLK); also elsewhere on the board

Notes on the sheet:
12 - Tuning Capacitor Bank 2/2
13 - Instrumentation Amplifier
11 - Tuning Capacitor Bank 1/2

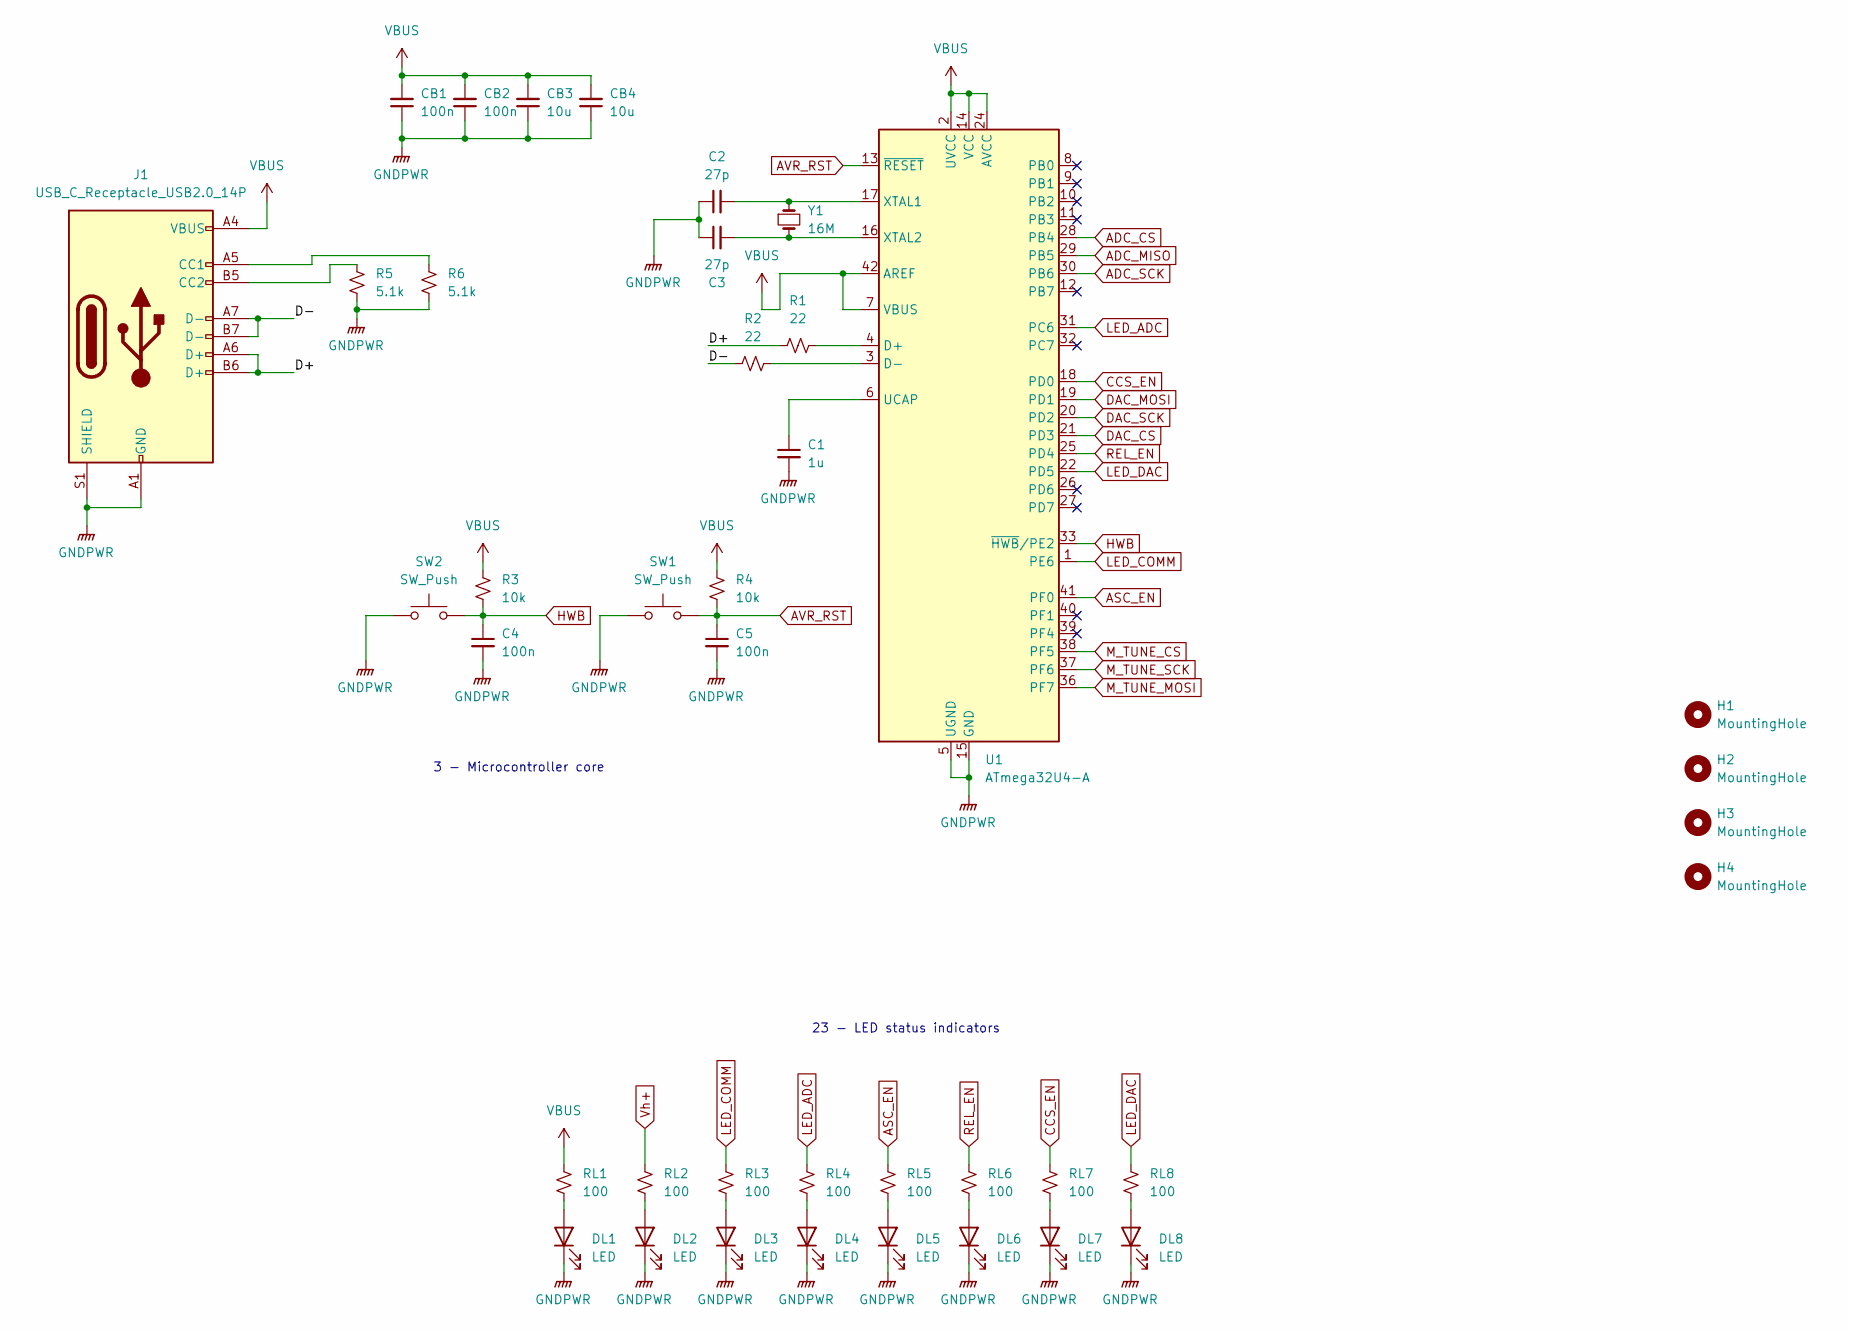
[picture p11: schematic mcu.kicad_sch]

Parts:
C1: 1u; C_0603_1608Metric_Pad1.08x0.95mm_HandSolder
C2, C3: 27p; C_0603_1608Metric_Pad1.08x0.95mm_HandSolder
C4, C5: 100n; C_0603_1608Metric_Pad1.08x0.95mm_HandSolder
CB1, CB2: 100n; C_0603_1608Metric_Pad1.08x0.95mm_HandSolder
CB3, CB4: 10u; C_0603_1608Metric_Pad1.08x0.95mm_HandSolder
DL1, DL2, DL3, DL4, DL5, DL6, DL7, DL8: LED; LED_0603_1608Metric_Pad1.05x0.95mm_HandSolder
H1, H2, H3, H4: MountingHole; MountingHole_3.2mm_M3_ISO7380_Pad
J1: USB_C_Receptacle_USB2.0_14P; USB_C_Receptacle_HCTL_HC-TYPE-C-16P-01A
R1, R2: 22; R_0603_1608Metric_Pad0.98x0.95mm_HandSolder
R3, R4: 10k; R_0603_1608Metric_Pad0.98x0.95mm_HandSolder
R5, R6: 5.1k; R_0603_1608Metric_Pad0.98x0.95mm_HandSolder
RL1, RL2, RL3, RL4, RL5, RL6, RL7, RL8: 100; R_0603_1608Metric_Pad0.98x0.95mm_HandSolder
SW1, SW2: SW_Push; SW_SPST_B3S-1000
U1: ATmega32U4-A; TQFP-44_10x10mm_P0.8mm
Y1: 16M; Crystal_SMD_Abracon_ABM7-2Pin_6.0x3.5mm

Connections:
/mcu/D+: J1.A6 (D+), J1.B6 (D+), R1.2
/mcu/D-: J1.A7 (D-), J1.B7 (D-), R2.2
ADC_CS: U1.28 (PB4); also elsewhere on the board
ADC_MISO: U1.29 (PB5); also elsewhere on the board
ADC_SCK: U1.30 (PB6); also elsewhere on the board
ASC_EN: RL5.1, U1.41 (PF0); also elsewhere on the board
AVR_RST: C5.1, R4.2, SW1.2, U1.13 (~RESET)
CCS_EN: RL7.1, U1.18 (PD0); also elsewhere on the board
DAC_CS: U1.21 (PD3); also elsewhere on the board
DAC_MOSI: U1.19 (PD1); also elsewhere on the board
DAC_SCK: U1.20 (PD2); also elsewhere on the board
GNDPWR: C1.2, C2.1, C3.1, C4.2, C5.2, CB1.1, CB2.1, CB3.1, CB4.1, DL1.1 (K), DL2.1 (K), DL3.1 (K), DL4.1 (K), DL5.1 (K), DL6.1 (K), DL7.1 (K), DL8.1 (K), J1.A1 (GND), J1.A12 (GND), J1.B1 (GND), J1.B12 (GND), J1.S1 (SHIELD), R5.2, R6.2, SW1.1, SW2.1, U1.5 (UGND), U1.15 (GND), U1.23 (GND), U1.35 (GND), U1.43 (GND); also elsewhere on the board
HWB: C4.1, R3.2, SW2.2, U1.33 (~HWB/PE2)
LED_ADC: RL4.1, U1.31 (PC6)
LED_COMM: RL3.1, U1.1 (PE6)
LED_DAC: RL8.1, U1.22 (PD5)
M_TUNE_CS: U1.38 (PF5); also elsewhere on the board
M_TUNE_MOSI: U1.36 (PF7); also elsewhere on the board
M_TUNE_SCK: U1.37 (PF6); also elsewhere on the board
unnamed: DL1.2 (A), RL1.2
unnamed: DL2.2 (A), RL2.2
unnamed: DL3.2 (A), RL3.2
unnamed: DL4.2 (A), RL4.2
unnamed: DL5.2 (A), RL5.2
unnamed: DL6.2 (A), RL6.2
unnamed: DL7.2 (A), RL7.2
unnamed: DL8.2 (A), RL8.2
unnamed: J1.A5 (CC1), R6.1
unnamed: J1.B5 (CC2), R5.1
unnamed: R1.1, U1.4 (D+)
unnamed: R2.1, U1.3 (D-)
unnamed: C1.1, U1.6 (UCAP)
unnamed: C2.2, U1.17 (XTAL1), Y1.1
unnamed: C3.2, U1.16 (XTAL2), Y1.2
REL_EN: RL6.1, U1.25 (PD4); also elsewhere on the board
VBUS: CB1.2, CB2.2, CB3.2, CB4.2, J1.A4 (VBUS), J1.A9 (VBUS), J1.B4 (VBUS), J1.B9 (VBUS), R3.1, R4.1, RL1.1, U1.2 (UVCC), U1.7 (VBUS), U1.14 (VCC), U1.24 (AVCC), U1.34 (VCC), U1.42 (AREF), U1.44 (AVCC); also elsewhere on the board
Vh+: RL2.1; also elsewhere on the board

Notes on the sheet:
23 - LED status indicators
3 - Microcontroller core

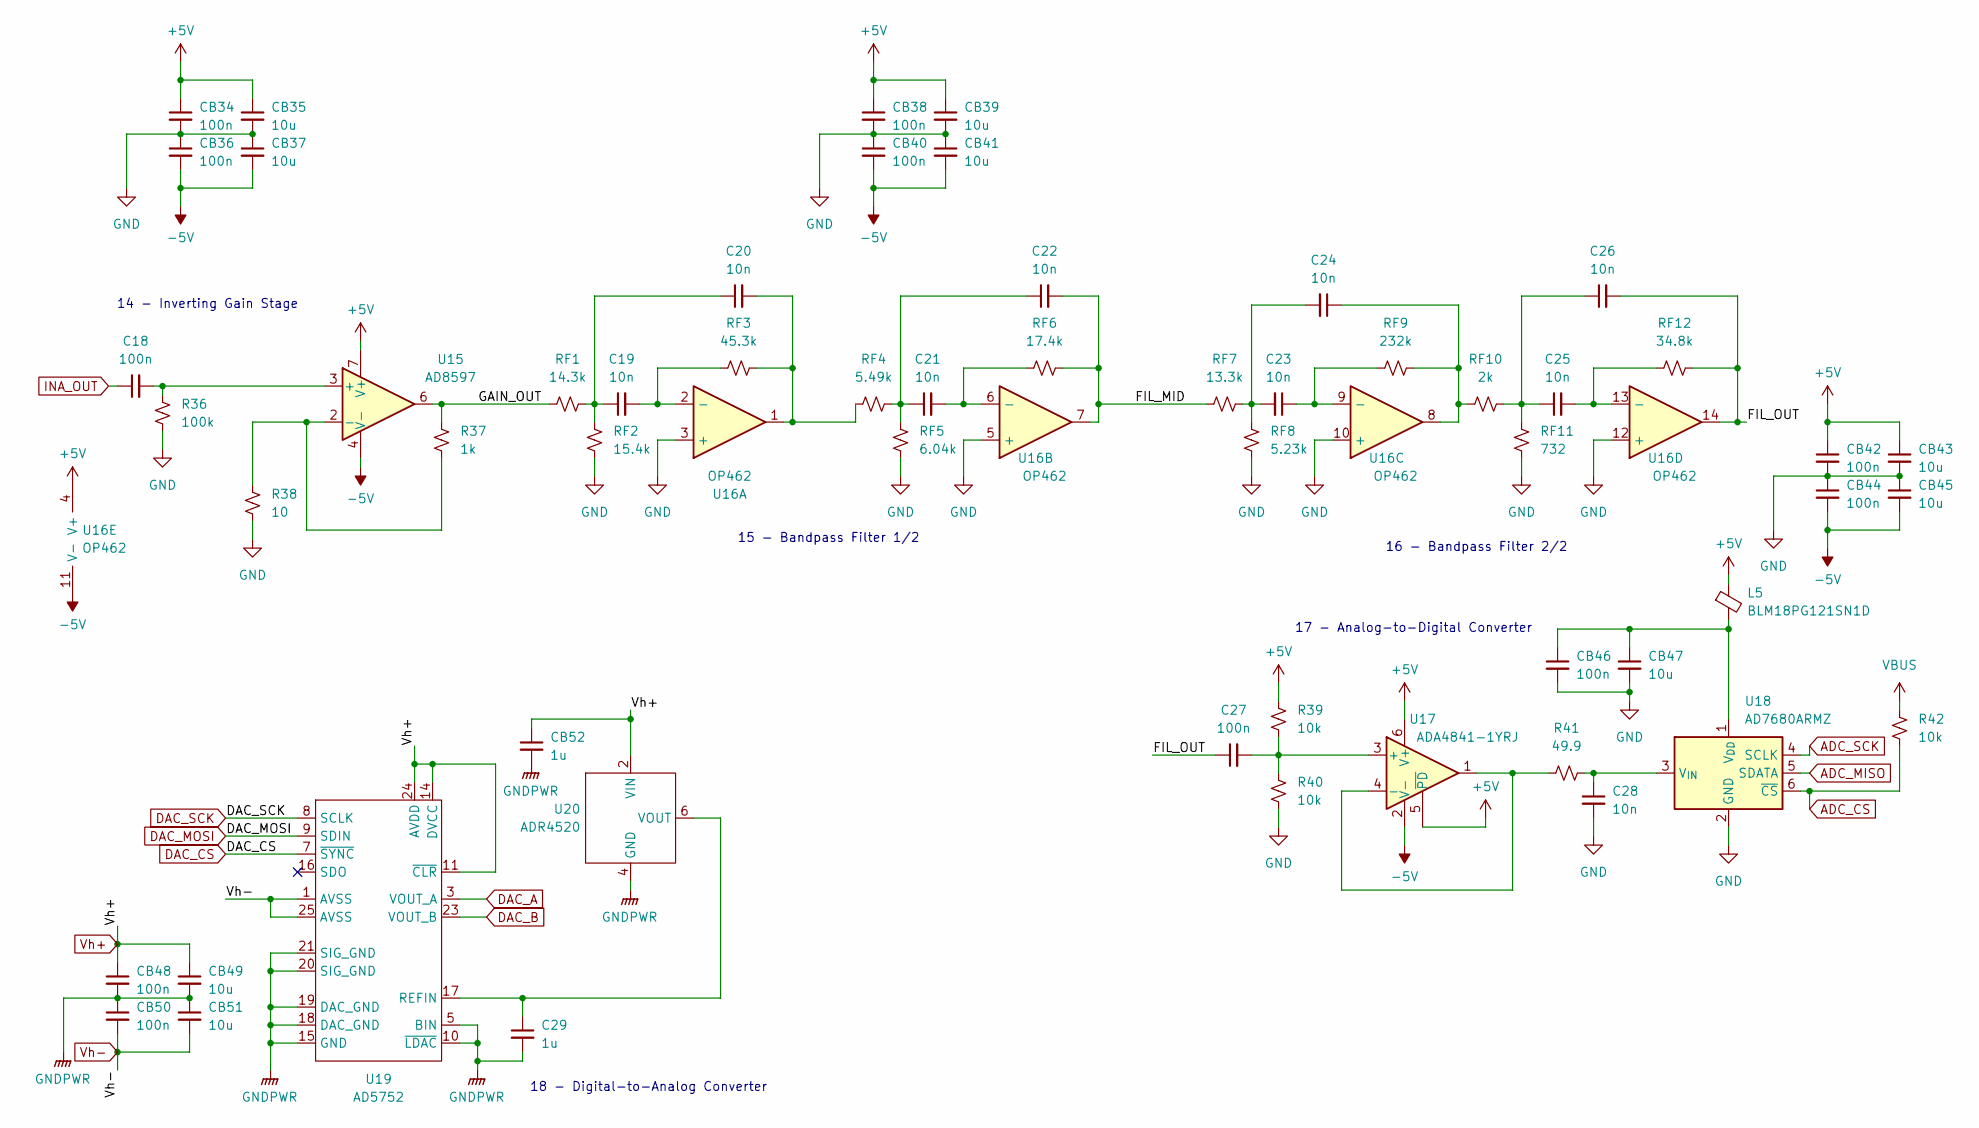
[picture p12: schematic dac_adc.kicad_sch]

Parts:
C18, C27: 100n; C_0603_1608Metric_Pad1.08x0.95mm_HandSolder
C19, C20, C21, C22, C23, C24, C25, C26, C28: 10n; C_0603_1608Metric_Pad1.08x0.95mm_HandSolder
C29: 1u; C_0603_1608Metric_Pad1.08x0.95mm_HandSolder
CB34, CB36, CB38, CB40, CB42, CB44, CB46, CB48, CB50: 100n; C_0603_1608Metric_Pad1.08x0.95mm_HandSolder
CB35, CB37, CB39, CB41, CB43, CB45, CB47, CB49, CB51: 10u; C_0603_1608Metric_Pad1.08x0.95mm_HandSolder
CB52: 1u; C_0603_1608Metric_Pad1.08x0.95mm_HandSolder
L5: BLM18PG121SN1D; L_0603_1608Metric_Pad1.05x0.95mm_HandSolder
R36: 100k; R_0603_1608Metric_Pad0.98x0.95mm_HandSolder
R37: 1k; R_0603_1608Metric_Pad0.98x0.95mm_HandSolder
R38: 10; R_0603_1608Metric_Pad0.98x0.95mm_HandSolder
R39, R40, R42: 10k; R_0603_1608Metric_Pad0.98x0.95mm_HandSolder
R41: 49.9; R_0603_1608Metric_Pad0.98x0.95mm_HandSolder
RF1: 14.3k; R_0603_1608Metric_Pad0.98x0.95mm_HandSolder
RF2: 15.4k; R_0603_1608Metric_Pad0.98x0.95mm_HandSolder
RF3: 45.3k; R_0603_1608Metric_Pad0.98x0.95mm_HandSolder
RF4: 5.49k; R_0603_1608Metric_Pad0.98x0.95mm_HandSolder
RF5: 6.04k; R_0603_1608Metric_Pad0.98x0.95mm_HandSolder
RF6: 17.4k; R_0603_1608Metric_Pad0.98x0.95mm_HandSolder
RF7: 13.3k; R_0603_1608Metric_Pad0.98x0.95mm_HandSolder
RF8: 5.23k; R_0603_1608Metric_Pad0.98x0.95mm_HandSolder
RF9: 232k; R_0603_1608Metric_Pad0.98x0.95mm_HandSolder
RF10: 2k; R_0603_1608Metric_Pad0.98x0.95mm_HandSolder
RF11: 732; R_0603_1608Metric_Pad0.98x0.95mm_HandSolder
RF12: 34.8k; R_0603_1608Metric_Pad0.98x0.95mm_HandSolder
U15: AD8597; SOIC-8_3.9x4.9mm_P1.27mm
U16: OP462; TSSOP-14_4.4x5mm_P0.65mm
U17: ADA4841-1YRJ; SOT-23-6
U18: AD7680ARMZ; SOT-23-6
U19: AD5752; HTSSOP-24-1EP_4.4x7.8mm_P0.65mm_EP3.2x5mm
U20: ADR4520; SOIC-8_3.9x4.9mm_P1.27mm

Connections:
+5V: CB34.1, CB35.1, CB38.1, CB39.1, CB42.1, CB43.1, L5.1, R39.1, U15.7 (V+), U16.4 (V+), U17.5 (~PD), U17.6 (V+); also elsewhere on the board
-5V: CB36.2, CB37.2, CB40.2, CB41.2, CB44.2, CB45.2, U15.4 (V-), U16.11 (V-), U17.2 (V-); also elsewhere on the board
/dac_adc/FIL_MID: C22.2, RF6.2, RF7.1, U16.7
/dac_adc/FIL_OUT: C26.2, C27.1, RF12.2, U16.14
/dac_adc/GAIN_OUT: R37.2, RF1.1, U15.6
ADC_CS: R42.2, U18.6 (~CS); also elsewhere on the board
ADC_MISO: U18.5 (SDATA); also elsewhere on the board
ADC_SCK: U18.4 (SCLK); also elsewhere on the board
DAC_A: U19.3 (VOUT_A); also elsewhere on the board
DAC_B: U19.23 (VOUT_B); also elsewhere on the board
DAC_CS: U19.7 (~SYNC); also elsewhere on the board
DAC_MOSI: U19.9 (SDIN); also elsewhere on the board
DAC_SCK: U19.8 (SCLK); also elsewhere on the board
GND: C28.2, CB34.2, CB35.2, CB36.1, CB37.1, CB38.2, CB39.2, CB40.1, CB41.1, CB42.2, CB43.2, CB44.1, CB45.1, CB46.2, CB47.2, R36.1, R38.1, R40.2, RF2.2, RF5.2, RF8.2, RF11.2, U16.3 (+), U16.5 (+), U16.10 (+), U16.12 (+), U18.2 (GND); also elsewhere on the board
GNDPWR: C29.2, CB48.2, CB49.2, CB50.1, CB51.1, CB52.2, U19.5 (BIN), U19.10 (~LDAC), U19.15 (GND), U19.18 (DAC_GND), U19.19 (DAC_GND), U19.20 (SIG_GND), U19.21 (SIG_GND), U20.4 (GND); also elsewhere on the board
INA_OUT: C18.1; also elsewhere on the board
unnamed: C19.1, C20.1, RF1.2, RF2.1
unnamed: C20.2, RF3.2, RF4.1, U16.1
unnamed: C21.1, C22.1, RF4.2, RF5.1
unnamed: C23.2, C24.2, RF7.2, RF8.1
unnamed: C24.1, RF9.2, RF10.1, U16.8
unnamed: C25.1, C26.1, RF10.2, RF11.1
unnamed: C18.2, R36.2, U15.3 (+)
unnamed: R37.1, R38.2, U15.2 (-)
unnamed: C19.2, RF3.1, U16.2 (-)
unnamed: C21.2, RF6.1, U16.6 (-)
unnamed: C23.1, RF9.1, U16.9 (-)
unnamed: C25.2, RF12.1, U16.13 (-)
unnamed: C27.2, R39.2, R40.1, U17.3 (+)
unnamed: R41.2, U17.1, U17.4 (-)
unnamed: CB46.1, CB47.1, L5.2, U18.1 (V_{DD})
unnamed: C28.1, R41.1, U18.3 (V_{IN})
unnamed: C29.1, U19.17 (REFIN), U20.6 (VOUT)
VBUS: R42.1; also elsewhere on the board
Vh+: CB48.1, CB49.1, CB52.1, U19.11 (~CLR), U19.14 (DVCC), U19.24 (AVDD), U20.2 (VIN); also elsewhere on the board
Vh-: CB50.2, CB51.2, U19.1 (AVSS), U19.25 (AVSS); also elsewhere on the board

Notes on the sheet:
18 - Digital-to-Analog Converter
14 - Inverting Gain Stage
15 - Bandpass Filter 1/2
17 - Analog-to-Digital Converter
16 - Bandpass Filter 2/2

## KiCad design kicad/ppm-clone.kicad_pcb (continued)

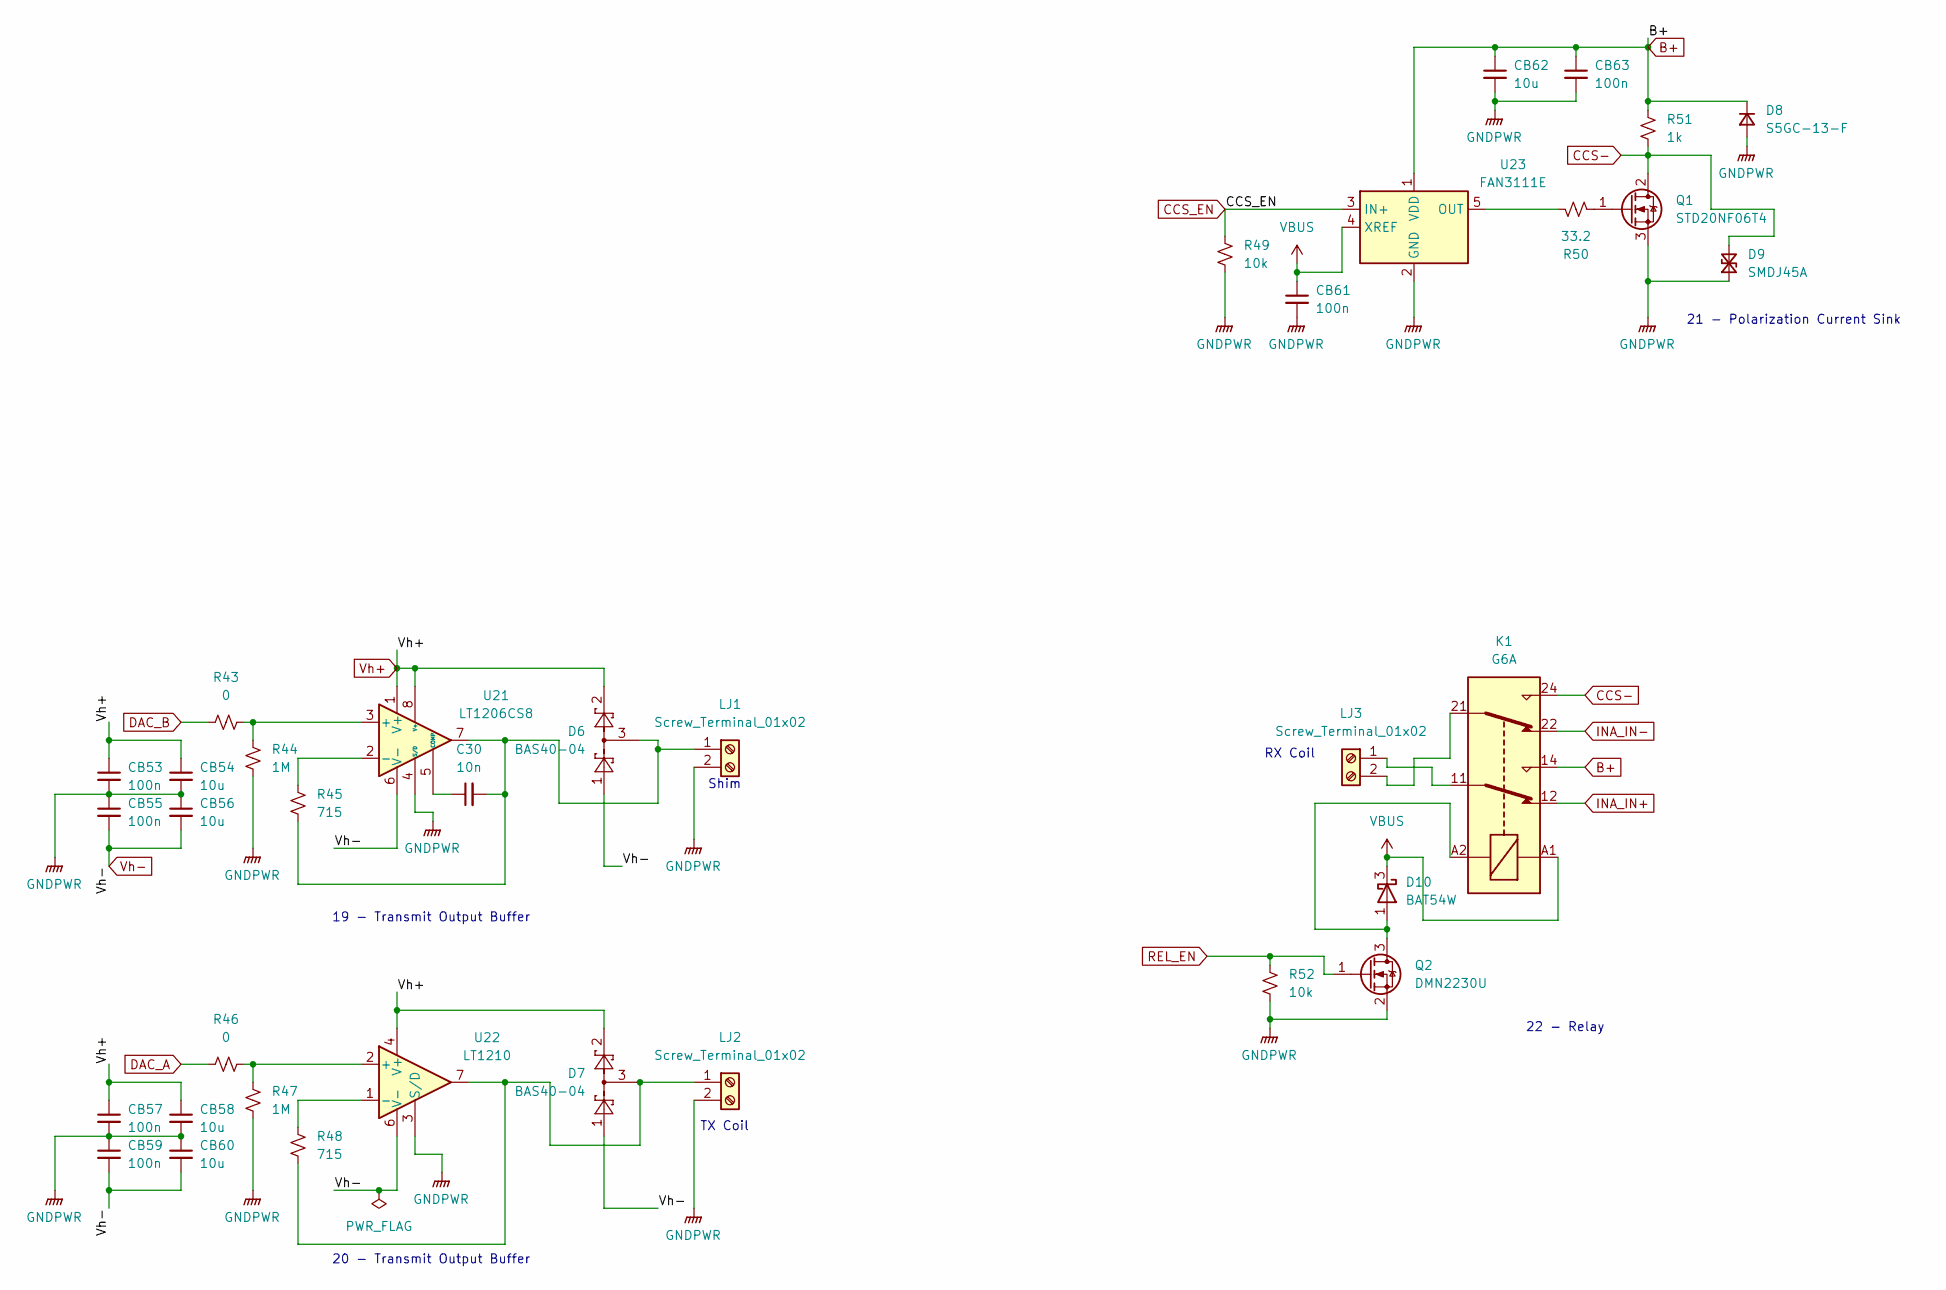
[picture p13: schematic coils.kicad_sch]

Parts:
C30: 10n; C_0603_1608Metric_Pad1.08x0.95mm_HandSolder
CB53, CB55, CB57, CB59, CB61, CB63: 100n; C_0603_1608Metric_Pad1.08x0.95mm_HandSolder
CB54, CB56, CB58, CB60, CB62: 10u; C_0603_1608Metric_Pad1.08x0.95mm_HandSolder
D6, D7: BAS40-04; SOT-23
D8: S5GC-13-F; D_SMC-RM10_Universal_Handsoldering
D9: SMDJ45A; D_SMC-RM10_Universal_Handsoldering
D10: BAT54W; SOT-323_SC-70
K1: G6A; Relay_DPDT_Omron_G6A
LJ1, LJ2, LJ3: Screw_Terminal_01x02; TerminalBlock_bornier-2_P5.08mm
Q1: STD20NF06T4; TO-252-2
Q2: DMN2230U; SOT-23
R43, R46: 0; R_0603_1608Metric_Pad0.98x0.95mm_HandSolder
R44, R47: 1M; R_0603_1608Metric_Pad0.98x0.95mm_HandSolder
R45, R48: 715; R_0603_1608Metric_Pad0.98x0.95mm_HandSolder
R49, R52: 10k; R_0603_1608Metric_Pad0.98x0.95mm_HandSolder
R50: 33.2; R_0603_1608Metric_Pad0.98x0.95mm_HandSolder
R51: 1k; R_0603_1608Metric_Pad0.98x0.95mm_HandSolder
U21: LT1206CS8; SO-8_3.9x4.9mm_P1.27mm
U22: LT1210; TO-263-7_TabPin4
U23: FAN3111E; SOT-23-5

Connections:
B+: CB62.1, CB63.1, D8.1 (K), K1.14, R51.1, U23.1 (VDD); also elsewhere on the board
CCS-: D9.2 (A2), K1.24, Q1.2 (D), R51.2
CCS_EN: R49.1, U23.3 (IN+); also elsewhere on the board
DAC_A: R46.1; also elsewhere on the board
DAC_B: R43.1; also elsewhere on the board
GNDPWR: CB53.2, CB54.2, CB55.1, CB56.1, CB57.2, CB58.2, CB59.1, CB60.1, CB61.2, CB62.2, CB63.2, D8.2 (A), D9.1 (A1), LJ1.2, LJ2.2, Q1.3 (S), Q2.2 (S), R44.2, R47.2, R49.2, R52.2, U21.4 (S/D), U22.3 (S/D), U23.2 (GND); also elsewhere on the board
INA_IN+: K1.12; also elsewhere on the board
INA_IN-: K1.22; also elsewhere on the board
unnamed: D10.1 (A), K1.A2, Q2.3 (D)
unnamed: C30.2, D6.3, LJ1.1, R45.2, U21.7
unnamed: D7.3, LJ2.1, R48.2, U22.7
unnamed: K1.11, LJ3.1
unnamed: K1.21, LJ3.2
unnamed: Q1.1 (G), R50.2
unnamed: R43.2, R44.1, U21.3 (+)
unnamed: R45.1, U21.2 (-)
unnamed: C30.1, U21.5 (COMP)
unnamed: R46.2, R47.1, U22.2 (+)
unnamed: R48.1, U22.1 (-)
unnamed: R50.1, U23.5 (OUT)
REL_EN: Q2.1 (G), R52.1; also elsewhere on the board
VBUS: CB61.1, D10.3 (K), K1.A1, U23.4 (XREF); also elsewhere on the board
Vh+: CB53.1, CB54.1, CB57.1, CB58.1, D6.2, D7.2, U21.1 (V+), U21.8 (V+), U22.4 (V+); also elsewhere on the board
Vh-: CB55.2, CB56.2, CB59.2, CB60.2, D6.1, D7.1, U21.6 (V-), U22.6 (V-); also elsewhere on the board

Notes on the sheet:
22 - Relay
Shim
19 - Transmit Output Buffer
21 - Polarization Current Sink
RX Coil
TX Coil
20 - Transmit Output Buffer

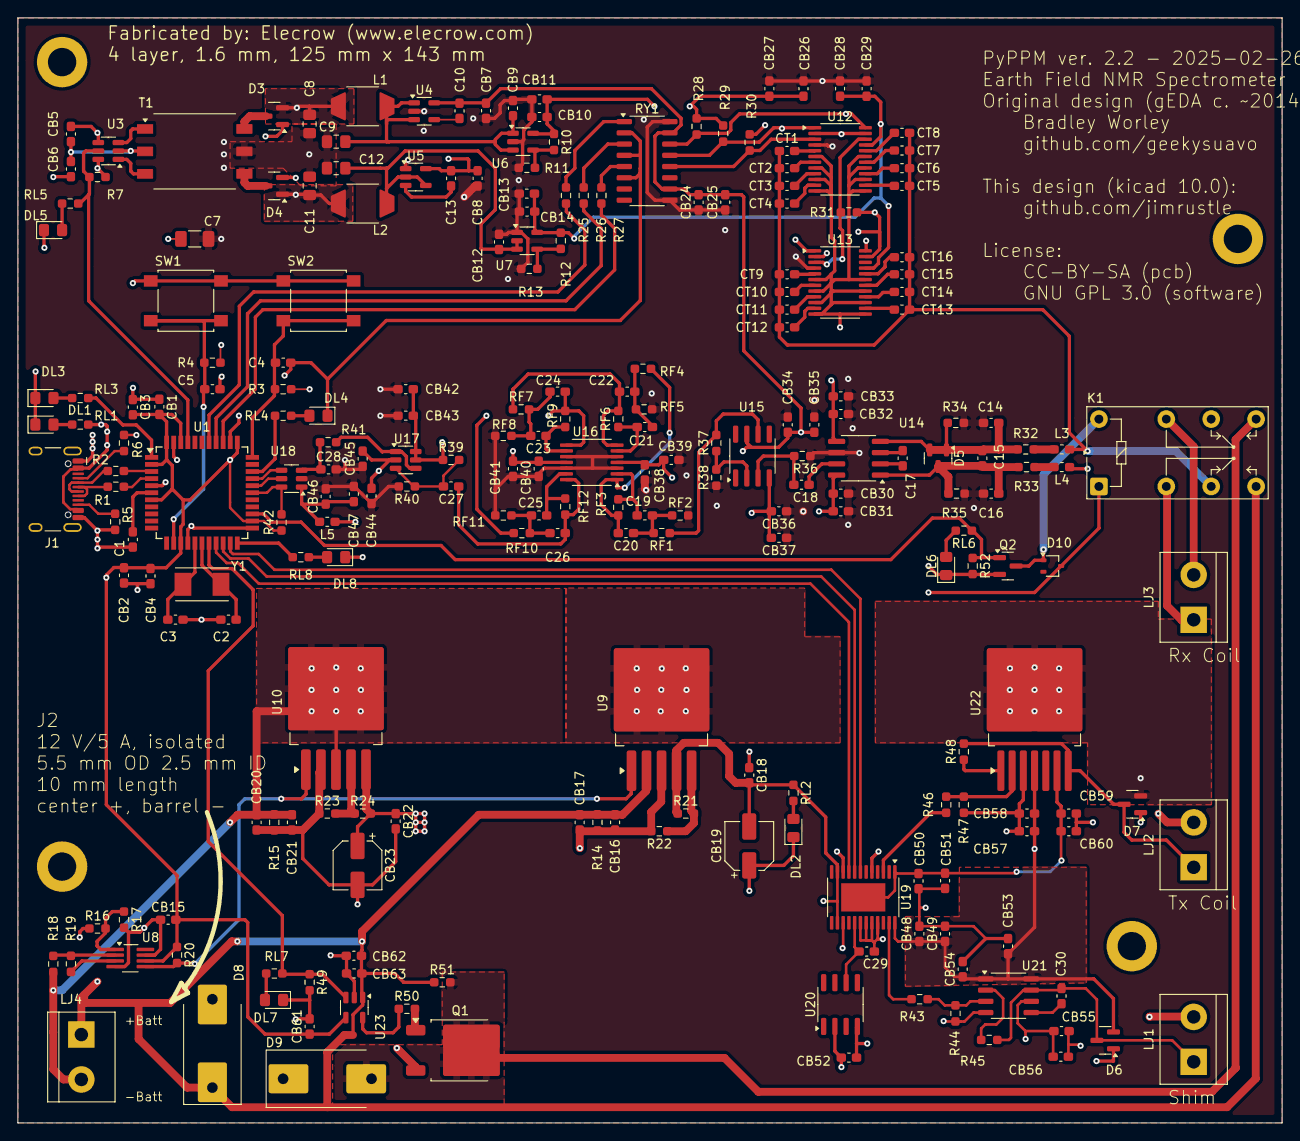
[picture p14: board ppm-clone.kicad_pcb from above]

Board: 4 copper layers, 143.0 x 125.0 mm, 237 parts (0 on the bottom side), 130 nets.

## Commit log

2026-07-18 add kicad project files
    [coils.kicad_sch, dac_adc.kicad_sch, mcu.kicad_sch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]
2026-07-18 add kicad cache files to gitignore
2026-07-18 move project to kicad folder
    [coils.kicad_sch]
2026-07-18 save and update project to kicad 10
    [coils.kicad_sch, dac_adc.kicad_sch, mcu.kicad_sch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]
2026-07-18 add schematic PDF

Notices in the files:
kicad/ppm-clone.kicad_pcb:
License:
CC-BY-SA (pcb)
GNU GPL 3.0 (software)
